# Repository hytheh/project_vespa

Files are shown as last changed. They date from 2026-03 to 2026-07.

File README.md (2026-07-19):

# Projet V.E.S.P.A. — prototype mk.2

**V**ision-**E**nabled **S**entry for the **P**rotection of **A**piaries

Tourelle optronique autonome de suivi prédictif par stéréo-vision, destinée à détecter,
suivre et neutraliser le frelon asiatique (*Vespa velutina nigrithorax*) en vol aux abords
d'une ruche, à l'aide d'un laser de puissance à collimation dynamique.

Projet de fin d'études — **ENSIL-ENSCI, Limoges** — filière Mécatronique (MIX 5), promotion 2026.
Antonin Delmas, Clément Desmedt, Clément Gilson — encadrement : Michel Ousset, Thierry Cortier.

> ### ⚠️ Statut : prototype semi-fonctionnel — projet clôturé, ouvert à reprise
>
> Ce dépôt est **archivé en l'état** à la fin du projet de fin d'études. Il est structuré
> et documenté pour être **repris par une équipe suivante**. Il n'est pas un produit fini :
> voir [État d'avancement](#état-davancement) et surtout
> **[docs/Difficultes_techniques.pdf](docs/Difficultes_techniques.pdf)**, qui recense les
> verrous levés et ceux qui restent ouverts.
>
> **Le laser de puissance (diode bleue 5,5 W — Classe 4) n'a jamais été mis sous tension.**
> C'était une décision de sécurité délibérée : le *watchdog* matériel qui conditionne
> l'autorisation de tir n'a jamais été implémenté. Ne pas alimenter la diode avant
> d'avoir lu [docs/annexes/securite_laser.md](docs/annexes/securite_laser.md).

---

## Documents

| Document | Contenu |
|---|---|
| **[Rapport technique](docs/Rapport_technique.pdf)** | Tout ce qu'il faut pour **reproduire** le système : matériel, câblage, système d'exploitation, firmware, compilation, calibration, mise en route. |
| **[Difficultés techniques](docs/Difficultes_techniques.pdf)** | Les **verrous non triviaux** rencontrés : ceux qui ont été levés (et comment), ceux qui ont été reportés (et pourquoi). À lire avant toute reprise. |
| **[Bibliographie](docs/Bibliographie.pdf)** | Sources du projet (biologie, vision, commande, optique, sécurité laser, matériel), chacune annotée de ce qu'elle a déterminé. Source BibTeX : [`docs/src/vespa.bib`](docs/src/vespa.bib). |
| [Rapport de PFE (soutenance)](docs/Rapport_PFE_2026_VESPA.pdf) | Le rapport rendu à la soutenance (mars 2026). Document historique, conservé tel quel. |

Annexes techniques (formats légers, tenus à jour avec le code) :
[protocole CAN](docs/annexes/protocole_can.md) ·
[câblage](docs/annexes/cablage.md) ·
[nomenclature / BOM](docs/annexes/bom.md) ·
[configuration Jetson](docs/annexes/jetson_setup.md) ·
[sécurité laser](docs/annexes/securite_laser.md) ·
[dette technique](docs/annexes/dette_technique.md)

---

## Architecture

Trois nœuds sur un bus **CAN 2.0B à 500 kbit/s**, plus un système auxiliaire de supervision.

```
                    ┌──────────────────────────────┐
                    │  VISION NODE                 │
                    │  Jetson Orin Nano Super 8 Go │
                    │  2x OV9281 global shutter    │
                    │  Stéréo 60 Hz + Kalman       │──┐
                    └──────────────────────────────┘  │
                                                      │
    ┌─────────────────────────────────┐               │   BUS CAN
    │  MOTION NODE                    │               │   500 kbit/s
    │  NUCLEO-G431RB                  │───────────────┤   11 bits
    │  2x X-NUCLEO-IHM16M1 (STSPIN830)│               │
    │  2x GM5208-12 + AS5048A · FOC   │               │
    └─────────────────────────────────┘               │
                                                      │
    ┌─────────────────────────────────┐               │
    │  COORDINATION NODE   ⚠ ABSENT   │───────────────┘
    │  ESP32 · collimation + tir      │
    │  + Watchdog (jamais implémenté) │
    └─────────────────────────────────┘
```

| Nœud | Cible | Rôle | État |
|---|---|---|---|
| **[vision_node](software/vision_node/)** | Jetson Orin Nano | Acquisition stéréo synchronisée matériellement (60 Hz), détection, triangulation, prédiction de Kalman, émission de la consigne | ✅ Fonctionnel (cible ArUco) |
| **[motion_node](software/motion_node/)** | STM32G431RB | Asservissement FOC en boucle fermée des deux axes pan/tilt sur la consigne reçue par CAN (la cinématique inverse `X,Y,Z → pan,tilt` est faite côté vision) | ✅ Servo FOC fonctionnel · intégration vision→moteur câblée, non validée sur banc |
| **[coordination_node](software/coordination_node/)** | ESP32 | Collimation dynamique, séquence de tir, **watchdog** et autorisation de tir | ❌ **Non implémenté** |
| **[common](software/common/)** | tous | Protocole CAN partagé (source unique de vérité) | ✅ Fonctionnel |

---

## État d'avancement

**Ce qui fonctionne, validé sur matériel réel :**

- **Vision.** Paire stéréo OV9281 déclenchée par le **PWM matériel du Tegra** (60 Hz), avec une
  dérive inter-caméras mesurée à **0,000 ms**. Chaîne zéro-copie V4L2 (mmap), suivi de cible,
  triangulation stéréo éparse, filtre de Kalman prédictif, émission des trames CAN.
- **Mouvement.** Asservissement FOC en boucle fermée des deux moteurs *pancake* GM5208-12
  sur encodeurs absolus AS5048A 14 bits. Butées logicielles, filtre de trajectoire,
  arrêt d'urgence matériel latché. Précision théorique 0,022°.
- **Protocole CAN.** Sérialisation/désérialisation partagée, développée sur bus virtuel
  `vcan0` puis **portée sur le bus physique sans changer une ligne**. Le Jetson a reçu
  **111 909 trames du STM32, sans une seule erreur** (`ip -s link show can0`, 21 mars 2026).

**Ce qui ne fonctionne pas, et pourquoi :**

| Verrou | Nature | Détail |
|---|---|---|
| 🟠 **Bus CAN — persistance** | À remettre en service | Le bus **a fonctionné** sur cuivre. `can0-pinmux.dtbo` est dans `/boot`, copie de référence dans [`jetson/dts/`](jetson/dts/). Piège : une mise à jour JetPack peut **effacer l'*overlay* de `/boot`** sans toucher à la ligne `OVERLAYS` qui le référence — le *bootloader* **n'émet aucune erreur**, `can0` existe toujours, mais ses broches restent `(MUX UNCLAIMED)` et le nœud émet dans le vide. **C'est une remise en état, pas une recherche** : remonter les transceivers avec le correctif 5 V, puis reconfirmer le sens émission. |
| 🔴 **Reconnaissance biologique** | Reporté | Le modèle **VespAI** est entraîné en RGB ; les capteurs sont monochromes. Le portage en Y8 (1 canal) produit un modèle rapide (10,3 ms, 100 fps) mais **inexploitable** : faux positifs massifs, incapacité à distinguer *V. velutina* de *V. crabro*. Remplacé par un **marqueur ArUco** servant de cible de substitution. |
| 🔴 **Tir laser** | Reporté (sécurité) | Aucun tir n'a été effectué. Le *watchdog* qui conditionne l'autorisation de tir n'existe pas. |
| 🔴 **Nœud de coordination** | Non commencé | Collimation dynamique, séquence de tir, watchdog : spécifiés, jamais codés. |

Le détail complet — symptômes, causes racines, correctifs — est dans
**[Difficultés techniques](docs/Difficultes_techniques.pdf)**.

---

## Reprendre le projet : par où commencer

1. Lire **[Difficultés techniques](docs/Difficultes_techniques.pdf)** en entier. Beaucoup de
   pièges de ce système sont invisibles dans le code (transceivers CAN contrefaits, broche
   `PA2` qui coupe la liaison série, impédance interne cachée de 4 kΩ sur le GPIO du Jetson…).
2. Reproduire l'environnement avec le **[Rapport technique](docs/Rapport_technique.pdf)**.
3. Attaquer les chantiers dans cet ordre — c'est l'ordre des dépendances :

   | # | Chantier | Pourquoi d'abord |
   |---|---|---|
   | 1 | **Remettre le CAN physique en service** | Remonter les transceivers avec le correctif 5 V. Le bus a déjà fonctionné : c'est du remontage, pas du débogage. |
   | 2 | **Implémenter le watchdog** (ESP32) | Condition *sine qua non* de toute mise sous tension du laser Classe 4. |
   | 3 | **Constituer un jeu de données monochrome** et réentraîner un détecteur | Rend au système sa fonction biologique ; remplace le marqueur ArUco. |
   | 4 | **Collimation dynamique + essais optiques** | Loi de commande établie, mécanisme spécifié, jamais assemblé ni étalonné. |
   | 5 | **Gestion multi-cibles** | Un seul filtre de Kalman aujourd'hui ; il en faut un par cible + association de données. |

---

## Structure du dépôt

```
project_vespa/
├── docs/                    Rapports (PDF + sources LaTeX), annexes, bibliographie, références
│   ├── src/                 Sources LaTeX + vespa.bib + figures (figs/)
│   ├── annexes/             Câblage, protocole CAN, BOM, setup Jetson, sécurité, dette technique
│   └── references/          Articles, datasheets, études préparatoires (IA)
├── hardware/
│   └── mechanical/          CAO : assemblages STEP, maillages imprimés, plateaux PrusaSlicer, moteur — voir son README
│                            (les modèles éditables restent sur le 3DEXPERIENCE de l'école)
├── jetson/                  Configuration système du Jetson (overlays, services CAN, extlinux)
├── simulation/              Scripts MATLAB de dimensionnement (vision + optique laser)
└── software/
    ├── common/              Protocole CAN partagé (C, portable STM32/ESP32/Linux)
    ├── vision_node/         Jetson — C++17 / OpenCV / V4L2 / SocketCAN (CMake)
    ├── motion_node/         STM32G431RB — SimpleFOC / FDCAN (PlatformIO)
    ├── coordination_node/   ESP32 — non implémenté (spécification uniquement)
    ├── tools/               Outils de maintenance : calibration stéréo, exposition, viewport
    └── legacy_mk1_bench/    Banc de caractérisation mk.1 (Arduino Uno) — annexes du rapport PFE
```

---

## Démarrage rapide

Prérequis : Jetson Orin Nano sous **JetPack 6.2.1**, avec le noyau Arducam et les *overlays*
installés (voir [configuration Jetson](docs/annexes/jetson_setup.md) — cette étape n'est
**pas** optionnelle, les caméras ne fonctionnent pas sans).

```bash
# --- Nœud de vision (Jetson) ---
sudo apt install libopencv-dev libi2c-dev libzmq3-dev cppzmq-dev nlohmann-json3-dev v4l-utils can-utils
cd software/vision_node && mkdir -p build && cd build
cmake .. && make -j6
sudo ./vision_node                 # accès requis à /sys/class/pwm et /dev/video*

# --- Nœud de mouvement (STM32, depuis le PC de développement) ---
cd software/motion_node
pio run -t upload                  # sonde ST-LINK
pio device monitor -b 115200

# --- Outils de maintenance (Jetson, headless : interface web) ---
# Les serveurs web n'écoutent QUE sur localhost (127.0.0.1). Sur un Jetson
# headless, y accéder par un tunnel SSH : ssh -L 5002:localhost:5002 <jetson>
cd software/tools/calib_stereo && ./run_calibration.sh      # http://localhost:5002
```

> Le nœud de vision et l'outil de calibration d'exposition (`calib_exposition`) accèdent
> tous deux directement au bus I²C. Un verrou d'exclusion mutuelle
> (`/tmp/vespa_hardware.lock`) les empêche de le toucher en même temps : **lancer les deux à
> la fois échouera volontairement**, ce n'est pas un bug. (Les outils `calib_stereo` et
> `viewport_live` ne prennent pas le verrou : ils ne font que consommer le flux ZMQ d'un
> producteur C++ qui, lui, le détient.)

---

## Avertissement sécurité

L'effecteur prévu est une diode laser **bleue de 5,5 W — Classe 4 (IEC 60825-1)**. À la densité
de puissance visée (≈ 2 200 W/cm² sur un spot de 0,53 mm), il n'existe **aucune distance sûre
en intérieur** : lésions oculaires irréversibles y compris sur réflexion diffuse, brûlures
cutanées, risque d'incendie. Lunettes **OD7+ (190–550 nm)** et interlock matériel obligatoires.

⚠️ Le mécanisme de collimation dynamique réduit le risque d'**incendie** (seuil d'embrasement
franchi sur ≈ 50 mm autour de la cible), mais **pas** le risque **oculaire**, qui persiste sur
près de **200 m**. Ne pas se croire protégé par la défocalisation.

Le dispositif de tir de ce dépôt est **incomplet et non validé**. Voir
[docs/annexes/securite_laser.md](docs/annexes/securite_laser.md) avant toute manipulation.

---

## Licence

Le code et la documentation **originaux** de ce dépôt sont publiés sous licence **MIT**
(voir [`LICENSE`](LICENSE)) — cohérent avec le statut « ouvert à reprise ».

Composants tiers, sous leurs licences respectives :

- `software/vision_node/include/zmq.hpp` — **cppzmq 4.11.0**, licence MIT (en-tête conservé).
- Les articles scientifiques de `docs/references/articles/` restent la propriété de leurs
  auteurs/éditeurs ; ceux conservés ici sont en Open Access **CC-BY**. Les *datasheets*
  constructeurs (`docs/references/datasheets/`) appartiennent à leurs fabricants respectifs.

Pour reprendre le projet, voir [`CONTRIBUTING.md`](CONTRIBUTING.md). Pour le citer, voir
[`CITATION.cff`](CITATION.cff).

---

## Note sur l'usage de l'IA

Ce projet a été développé avec une assistance importante de modèles de langage (rédaction,
débogage, état de l'art), comme documenté dans le préambule du rapport de PFE. Les archives
de conversations ayant mené à la résolution des verrous clés ont été conservées et ont servi
à rédiger le document [Difficultés techniques](docs/Difficultes_techniques.pdf).
Plusieurs verrous majeurs — transceivers CAN contrefaits, impédance cachée du GPIO,
profondeur de champ létale réelle — ont été identifiés **contre** l'avis de l'IA, par la mesure.

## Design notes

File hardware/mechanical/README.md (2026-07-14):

# Mécanique — CAO et pièces imprimées 3D

Géométrie du prototype VESPA mk.2 : assemblages STEP, maillages imprimés, projets
PrusaSlicer qui les ont produits.

```
hardware/mechanical/
├── cad/            assemblages STEP (AP242, mm)
├── print/          maillages des pièces imprimées (STL / 3MF)
│   └── plates/     projets PrusaSlicer des plateaux lancés
└── motor/          caractérisation du moteur GM5208-12
```

---

## Fichiers éditables

La CAO est faite sous **3DEXPERIENCE R2026x**, sur la **plateforme privée de l'école**.
Chez Dassault Systèmes les objets natifs (`3D Shape`, `Physical Product`) sont des
enregistrements de base de données, pas des fichiers : ils ne sortent pas de la plateforme.

**Les modèles paramétriques — arbre de construction, esquisses, contraintes — sont sur le
3DEXPERIENCE de l'école, et nulle part ailleurs.** La colonne *Item 3DX* des tableaux
ci-dessous donne, pour chaque pièce, le nom sous lequel elle y est enregistrée : c'est la
clé de recherche dans la base.

Ce qui sort de la plateforme, et qui est ici, est l'export **STEP** (ISO 10303 AP242) :
géométrie exacte — surfaces, arêtes, topologie — lisible par SolidWorks, Fusion, FreeCAD,
Onshape, CATIA. Il porte la géométrie, pas l'historique de conception. Les maillages
(`.stl`, `.3mf`) ne portent ni l'un ni l'autre.

---

## Convention de nommage

```
VESPA_<Sous-ensemble>_<Pièce>_<Révision>.<ext>
```

| Champ | Règle | Exemple |
|---|---|---|
| `Sous-ensemble` | Où la pièce se monte | `Turret`, `Frame`, `Link`, `Base`, `Camera`, `Optics` |
| `Pièce` | Ce qu'elle est | `MotorMount`, `FrontShield`, `LinkC` |
| `Révision` | Lettre.chiffre, croissante | `A.1`, `A.2`, `A.3` |

Les assemblages prennent `ASY` comme sous-ensemble ; le suffixe `_WIP` marque un assemblage
inachevé. Les plateaux d'impression sont préfixés `PLATE_`.

Les noms d'origine (préfixe `ADEL_`, espaces, parenthèses) ont été normalisés. Le nom
d'origine est conservé dans la colonne *Item 3DX* : c'est la clé de recherche dans la base
de l'école.

---

## Assemblages — `cad/`

| Fichier | Item 3DX | Rév. | Contenu | État |
|---|---|---|---|---|
| [`VESPA_ASY_FrameBase_A.2.step`](cad/VESPA_ASY_FrameBase_A.2.step) | `ADEL_VESPA_Frame_Base_ASY` | A.2 | **Le démonstrateur présenté** : tourelle 2 axes, 2× GM5208-12, module laser non câblé, 6× roulement 604ZZ. Les caméras n'y sont pas modélisées | Assemblé, monté |
| [`VESPA_ASY_Turret_A.2_WIP.step`](cad/VESPA_ASY_Turret_A.2_WIP.step) | `ADEL_VESPA_ASY_Turret` | A.2 | **Produit complet** : Jetson Orin Nano, 2× OV9281, laser, et le **tube optique** — lentille Ø63 f100 sur bague, portée par l'actionneur linéaire 35 mm : c'est le mécanisme de collimation dynamique | Inachevé, jamais assemblé |
| [`VESPA_ASY_Base_A.1_WIP.step`](cad/VESPA_ASY_Base_A.1_WIP.step) | `ADEL_VESPA_ASY_Base_mk2` | A.1 | Embase du produit complet : moyeu + jambe | Inachevé, jamais imprimé |
| [`VESPA_Bench_BoardPlate_A.1.step`](cad/VESPA_Bench_BoardPlate_A.1.step) | `ADEL_VESPA_Board_Bench` | A.1 | Platine de banc, 160 × 246 × 52 mm, portant les cartes électroniques. Matériel d'établi, hors machine | — |

`VESPA_ASY_Turret_A.2_WIP.step` pèse **83 Mo** : l'essentiel est le modèle fournisseur du
kit de développement Jetson Orin Nano publié par NVIDIA, modélisé jusqu'aux résistances
0402. La géométrie propre à VESPA y est marginale en volume.

`cad/` ne contient **que des assemblages** : il n'existe pas d'export STEP pièce à pièce.
Une pièce seule s'obtient en l'isolant dans l'assemblage, ou depuis 3DEXPERIENCE.

---

## Index des pièces imprimées

Quantités telles que définies dans l'assemblage.

### Châssis 2 axes — `VESPA_ASY_FrameBase_A.2`

| Pièce | Qté | Maillage | Plateau | Item 3DX |
|---|---:|---|---|---|
| `Frame_BaseA` | 1 | [`A.2`](print/VESPA_Frame_BaseA_A.2.stl) | — | `ADEL_VESPA_Frame_BaseA` |
| `Frame_BaseB` | 1 | [`A.2`](print/VESPA_Frame_BaseB_A.2.stl) | — | `ADEL_VESPA_Frame_BaseB` |
| `Frame_JointB2` | 1 | [`A.1`](print/VESPA_Frame_JointB2_A.1.stl) | [`Structural_x4`](print/plates/PLATE_Structural_x4.3mf) | `ADEL_VESPA_Frame_JointB2` |
| `Frame_LinkB1` | 1 | [`A.1`](print/VESPA_Frame_LinkB1_A.1.stl) | — | `ADEL_VESPA_Frame_LinkB1` |
| `Frame_LinkC` | 1 | [`A.3`](print/VESPA_Frame_LinkC_A.3.stl) | — | `ADEL_VESPA_Frame_LinkC` |
| `Frame_LinkA` | 1 | ⬜ absent | — | `ADEL_VESPA_Frame_LinkA` |
| `Link_BracketLeft` | 1 | [`A.1`](print/VESPA_Link_BracketLeft_A.1.stl) | [`Structural_x4`](print/plates/PLATE_Structural_x4.3mf) | `ADEL_VESPA_Link_BracketLeft` |
| `Link_BracketRight` | 1 | [`A.1`](print/VESPA_Link_BracketRight_A.1.stl) | — | `ADEL_VESPA_Link_BracketRight` |
| `Turret_MotorPlate` | 1 | [`A.1`](print/VESPA_Turret_MotorPlate_A.1.stl) | [`Structural_x4`](print/plates/PLATE_Structural_x4.3mf) | `ADEL_VESPA_Turret_MotorPlate` |
| `Turret_BearingPlate` | 1 | [`A.1`](print/VESPA_Turret_BearingPlate_A.1.stl) | — | `ADEL_VESPA_Turret_BearingPlate` |
| `Turret_ShieldLite` | 1 | [`A.1`](print/VESPA_Turret_ShieldLite_A.1.stl) | [`Structural_x4`](print/plates/PLATE_Structural_x4.3mf) | `ADEL_VESPA_Turret_ShieldLite` |

### Tourelle complète — `VESPA_ASY_Turret_A.2_WIP`

| Pièce | Qté | Maillage | Plateau | Item 3DX |
|---|---:|---|---|---|
| `Turret_RailType1` | 2 | [`A.2`](print/VESPA_Turret_RailType1_A.2.3mf) | [`RailType1_x2`](print/plates/PLATE_RailType1_x2.3mf) | `ADEL_VESPA_Turret_Rail_Type1` |
| `Turret_RailType2` | 2 | [`A.2`](print/VESPA_Turret_RailType2_A.2.3mf) | [`RailType2_x2`](print/plates/PLATE_RailType2_x2.3mf) | `ADEL_VESPA_Turret_RailType2` |
| `Turret_XFrame1Top` | 2 | [`A.1`](print/VESPA_Turret_XFrame1Top_A.1.3mf) | — | `ADEL_VESPA_Turret_XFrame1Top` |
| `Turret_FrontShield` | 1 | [`A.1`](print/VESPA_Turret_FrontShield_A.1.3mf) | [`flat`](print/plates/PLATE_FrontShield_flat.3mf) · [`tilted`](print/plates/PLATE_FrontShield_tilted.3mf) | `ADEL_VESPA_Turret_FrontShield` |
| `Turret_MotorMount` | 1 | [`A.1`](print/VESPA_Turret_MotorMount_A.1.3mf) | [`BearingMount_MotorMount`](print/plates/PLATE_BearingMount_MotorMount.3mf) | `ADEL_VESPA_Turret_MotorMount` |
| `Turret_BearingMount` | 1 | ⬜ absent — géométrie dans le plateau | [`BearingMount_MotorMount`](print/plates/PLATE_BearingMount_MotorMount.3mf) | `ADEL_VESPA_Turret_BearingMount` |
| `Turret_LABracket` | 1 | [`A.1`](print/VESPA_Turret_LABracket_A.1.3mf) | — | `ADEL_VESPA_Turret_LABracket` |
| `Turret_LaserMountFront` | 1 | [`A.2`](print/VESPA_Turret_LaserMountFront_A.2.3mf) | — | `ADEL_VESPA_Turret_LaserMountFront` |
| `Turret_CamBracket` | 2 | ⬜ absent | — | `ADEL_VESPA_Turret_CamBracket` |
| `Turret_JetsonHolder_L` | 1 | ⬜ absent | — | `ADEL_VESPA_Turret_JetsonHolder_L` |
| `Turret_JetsonHolder_R` | 1 | ⬜ absent | — | `ADEL_VESPA_Turret_JetsonHolder_R` |
| `LensRing` | 1 | ⬜ absent | — | `ADEL_VESPA_LensRing` |
| `Linear35_CarriageBody` | 1 | ⬜ absent | — | `ADEL_VESPA_Linear35_CarriageBody` |

### Embase — `VESPA_ASY_Base_A.1_WIP`

| Pièce | Qté | Maillage | Plateau | Item 3DX |
|---|---:|---|---|---|
| `Base_Hub` | 1 | [`A.1`](print/VESPA_Base_Hub_A.1.stl) | — | `ADEL_VESPA_Base_Hub` |
| `Base_Leg` | 1 | ⬜ absent | — | `ADEL_VESPA_Base_Leg` |

### Hors assemblage

| Pièce | Maillage | Item 3DX | Statut |
|---|---|---|---|
| `Optics_LensHolderSpacer` | [`A.1`](print/VESPA_Optics_LensHolderSpacer_A.1.3mf) | `ADEL_VESPA_Temporary_LensHolderSpacer` | Cale provisoire de porte-lentille. Pièce d'appoint, n'apparaît dans aucun assemblage |
| `Camera_CarrierB` | [`A.1`](print/VESPA_Camera_CarrierB_A.1.3mf) | `ADEL_SK_Carrier_B` | Support de carte porteuse, 53 × 56 × 4,6 mm. Absent des assemblages A.2 |

**Légende :** ⬜ maillage absent du dépôt. La pièce existe dans le STEP ; son export
d'impression n'a pas été retrouvé.

---

## Paramètres d'impression

Imprimante **Prusa CORE One**, buse **0,4 mm haut débit**, **PLA**, couche **0,2 mm**,
plateau **60 °C**.

Les six fichiers de [`print/plates/`](print/plates/) sont des projets PrusaSlicer complets :
le `.3mf` contient l'orientation de pose, les supports et le profil utilisés.

| Plateau | Pièces | Profil | Remplissage | Périm. | Buse | Supports |
|---|---|---|---|---:|---:|---|
| [`PLATE_Structural_x4`](print/plates/PLATE_Structural_x4.3mf) | `Turret_MotorPlate`, `Turret_ShieldLite`, `Link_BracketLeft`, `Frame_JointB2` | `0.20mm STRUCTURAL` — **Prusament PLA** | gyroïde 25 % | 2 | 230 °C | peints |
| [`PLATE_RailType1_x2`](print/plates/PLATE_RailType1_x2.3mf) | 2× `Turret_RailType1` | `0.20mm SPEED` | gyroïde 25 % | 3 | 225 °C | peints |
| [`PLATE_RailType2_x2`](print/plates/PLATE_RailType2_x2.3mf) | 2× `Turret_RailType2` | `0.20mm SPEED` | gyroïde 25 % | 3 | 225 °C | peints |
| [`PLATE_FrontShield_flat`](print/plates/PLATE_FrontShield_flat.3mf) | `Turret_FrontShield`, pose à plat | `0.20mm SPEED` | gyroïde 25 % | 3 | 225 °C | peints |
| [`PLATE_FrontShield_tilted`](print/plates/PLATE_FrontShield_tilted.3mf) | `Turret_FrontShield`, pose inclinée | `0.20mm SPEED` | gyroïde 25 % | 3 | 225 °C | automatiques |
| [`PLATE_BearingMount_MotorMount`](print/plates/PLATE_BearingMount_MotorMount.3mf) | `Turret_BearingMount`, `Turret_MotorMount` | `0.20mm SPEED` | grille 15 % | 2 | 225 °C | automatiques |

Les deux plateaux `FrontShield` sont deux orientations de pose de la même pièce A.1.

`STRUCTURAL` est le seul profil en Prusament PLA à 230 °C, avec 4 couches pleines en fond ;
il porte les quatre pièces qui reprennent les efforts des moteurs. Les cinq autres plateaux
sont en `SPEED`. *Supports peints* = générés uniquement sur les zones marquées
(`support_material_auto = 0`).

---

## Composants du commerce présents dans la CAO

Modélisés pour l'encombrement et les fixations, **non fabriqués**. Références et prix dans
la [nomenclature](../../docs/annexes/bom.md).

| Composant | Item 3DX | Où |
|---|---|---|
| Moteur *pancake* GM5208-12 | `ADEL_VESPA_5208BLDC_ASY` | FrameBase (×2), Turret (×1) |
| Module laser 5,5 W — corps, carte, lentille, capot acrylique, ventilateur 40×15 | `ADEL_VESPA_ASY_Laser` | FrameBase, Turret |
| Jetson Orin Nano — kit de développement | `ADEL_NvidiaJetsonOrinNano` | Turret |
| Caméra OV9281 UC788B | `ADEL_VESPA_OV9281_CameraModuleUC788B` | Turret (×2) |
| Actionneur linéaire 35 mm — rails Ø3, douilles, moteur pas-à-pas 20 mm | `ADEL_VESPA_ASY_Linear35Actuator` | Turret |
| Lentille asphérique K9 Ø63 f100 | `ADEL_VESPA_Lens63d100f` | Turret |
| Roulements 604ZZ (×6) et 6810 (×1) | `ADEL_VESPA_604ZZ_Bearing`, `ADEL_VESPA_bearing_6810O` | FrameBase, Turret |
| Goupilles 4×20, vis CHc M4×40 | `ADEL_VESPA_HRDW_Pin4x20`, `ADEL_VESPA_Laser_~Vis_Chc_M4x40` | FrameBase |

---

## Moteur

[`motor/GM5208-12.json`](motor/GM5208-12.json) — caractérisation du moteur *pancake*
GM5208-12 au format ST Motor Profiler, exploitable directement par le
*ST Motor Control Workbench*.

| Paramètre | Valeur |
|---|---|
| Type | PMSM *pancake* (gimbal), 14 aimants |
| Paires de pôles | **7** |
| Résistance statorique `Rs` | 7,48 Ω |
| Inductance `Ls` | 4,49 mH |
| Tension nominale | 23,6 V |
| Courant nominal | 1,5 A |
| Constante de FEM | 32,96 |
| Encodeur associé | AS5048A, magnétique absolu **14 bits** (0,022°) |

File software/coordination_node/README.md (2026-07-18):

# `coordination_node` — NON IMPLÉMENTÉ

> **Ce nœud n'existe pas.** Ce dossier ne contient aucun code : uniquement sa spécification.
> Il est conservé dans l'arborescence parce que le protocole CAN réserve ses identifiants et
> que le reste du système est écrit en supposant son existence future.

**Cible matérielle prévue :** ESP32 **bi-cœur** (ESP32 classique ou ESP32-S3).

> ⚠️ L'ESP32-**C3** SuperMini listé dans la nomenclature d'origine est **mono-cœur**
> (RISC-V) : il ne peut pas fournir le « cœur CPU dédié » exigé par le watchdog ci-dessous.
> Deux options pour une reprise : (a) viser un ESP32/ESP32-S3 **bi-cœur** pour réserver un
> cœur au superviseur ; ou (b) sur mono-cœur, réaliser l'isolation par une **tâche FreeRTOS
> de priorité maximale épinglée** + le **watchdog matériel (TWDT)** de la puce. L'option (a)
> est recommandée pour un organe qui conditionne un laser de Classe 4.

---

## Pourquoi c'est le chantier n°2 de toute reprise

Ce nœud porte le **watchdog**. Le watchdog est la **condition *sine qua non*** de toute mise
sous tension du laser de Classe 4. Tant qu'il n'existe pas, **le laser ne doit pas être
alimenté** — et il ne l'a jamais été.

Voir [`docs/annexes/securite_laser.md`](../../docs/annexes/securite_laser.md).

---

## Les trois fonctions à implémenter

### 1. Watchdog (priorité absolue)

Superviseur centralisé, **sur un cœur CPU dédié** (voir la note matérielle ci-dessus), au
plus près de l'organe dangereux.

- Écoute les *heartbeats* périodiques de tous les nœuds : `HB_VISION` (`0x100`),
  `HB_MOTION` (`0x110`), `HB_COORD` (`0x120`).
- Chaque *heartbeat* porte un `uint8_t system_state` : `0x00` OK, `0x01` WARNING,
  `0x02` FAULT (énumération normative dans `can_protocol.h`).
- **Timeout par nœud (à figer) :** valeur proposée **200 ms** de silence glissant. Le
  firmware actuel émet les *heartbeats* à **1 Hz** (`motion_node`) ; pour un interlock à
  200 ms, il faut **relever la cadence** sur le lien critique (p. ex. ≥ 10 Hz), ce qui est
  un préalable d'implémentation.
- **Déclenche la mise en sécurité si** : un nœud signale `FAULT`, **ou** un nœud cesse
  d'émettre au-delà du *timeout* ci-dessus.
- **Signal d'interlock — ligne physique, pas une trame CAN.** Le superviseur pilote une
  sortie GPIO dédiée `INTERLOCK_EN`, **fail-safe** (niveau **bas = tir interdit** ; l'organe
  de tir n'est armé que sur niveau haut maintenu). Elle est **indépendante du bus** pour ne
  pas dépendre de la panne qu'elle doit traiter (cf. l'avertissement ci-dessous).
- La mise en sécurité est **matérielle** : coupure de l'**alimentation générale** et passage
  de `INTERLOCK_EN` au niveau bas. Pendant le temps de décharge des condensateurs, l'ordre
  de tir est en outre inhibé au niveau logiciel.

> ⚠️ Un superviseur qui dépendrait du bus pour couper le courant serait vulnérable à la
> panne même qu'il doit traiter. La coupure doit être physique et par défaut fermée
> (*fail-safe*).

### 2. Séquence de tir

- Consomme `FIRE_CMD` (`0x010`) émis par le `vision_node` — identifiant le plus faible du
  protocole, donc **priorité absolue** à l'arbitrage CAN.
- N'autorise le tir que si **toutes** les conditions sont réunies : cible verrouillée,
  watchdog nominal, interlock fermé, collimateur en position.

### 3. Collimation dynamique

- Pilote la lentille mobile **L2** (actionneur linéaire + TMC2209).
- Publie sa position absolue sur `POS_COORD` (`0x040`, `int32_t position_mm`).
- La **loi de commande est déjà établie** (relations de conjugaison de Descartes, approximée
  par un polynôme à 1e-4 mm près) — voir le rapport de soutenance §10.2 et
  `simulation/optique/Laser_Optics_v1.m`.

---

## Trames CAN réservées

| ID | Trame | Sens | Charge utile |
|---|---|---|---|
| `0x010` | `FIRE_CMD` | ← vision | `uint8_t fire_order` (`0x01` = tir) |
| `0x040` | `POS_COORD` | → vision | `int32_t position_mm` (collimateur) |
| `0x120` | `HB_COORD` | → (watchdog) | `uint8_t system_state` |
| `0x210` | `DBG_COORD` | → broadcast | Débogage |

Définition normative : [`software/common/can_protocol.h`](../common/can_protocol.h).
Le protocole est **partagé** — l'implémentation de ce nœud doit lier `software/common/`,
et surtout **ne pas redéfinir les structures**.

---

## Point de départ

Le code CAN est portable : `software/common/can_utils.c` compile sur STM32, ESP32 et Linux.
Un ESP32 dispose d'un contrôleur CAN natif (TWAI), compatible avec le bus 500 kbit/s du
projet, moyennant un transceiver.

⚠️ **Attention au transceiver.** Les modules WCMCU-230 approvisionnés pour le projet sont
des **contrefaçons 5 V** vendues pour des SN65HVD230 3,3 V (boîtiers poncés et re-marqués).
Ils fonctionnent, mais **alimentés en 5 V**, avec un pont diviseur 1 kΩ / 2 kΩ sur la sortie
`CRX`. Vérifier ce que vous avez en main avant de câbler — voir
[`docs/annexes/bom.md`](../../docs/annexes/bom.md).

Le plus simple pour démarrer reste de développer sur `vcan0`, comme l'ont fait les autres
nœuds : l'interface est indiscernable d'un bus réel côté SocketCAN, et le passage au matériel
n'a demandé aucune modification du code. Voir
[`docs/Difficultes_techniques.pdf`](../../docs/Difficultes_techniques.pdf).

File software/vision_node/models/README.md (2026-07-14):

# `models/` — moteur d'inférence de la voie abandonnée

## `vespai.engine` (16 Mo)

Moteur **TensorRT sérialisé** issu du portage du modèle **VespAI**
([O'Shea-Wheller et al., 2024](../../../docs/references/articles/OSheaWheller2024_VespAI_CommsBiology.pdf)),
construit sur le Jetson Orin Nano du projet.

> **Ce fichier n'est utilisé par aucun code du dépôt.** Ni le `CMakeLists.txt`, ni
> `vision_node`, ni aucun outil ne le chargent. Il est conservé comme **trace de la voie
> d'inférence explorée puis abandonnée**, pas comme un composant du système livré.

### Pourquoi il n'est pas utilisé

VespAI est entraîné en **RGB** ; les capteurs OV9281 du projet sont **monochromes**. Le
portage en Y8 (1 canal) produit un modèle **rapide** — 10,3 ms par inférence, soit 100 fps,
donc parfaitement compatible avec la cadence de 60 Hz — mais **inexploitable en pratique** :
faux positifs massifs, et incapacité à distinguer *Vespa velutina* de *Vespa crabro*, ce qui
est précisément la discrimination que le système doit faire.

La détection biologique a donc été remplacée par un **marqueur ArUco** servant de cible de
substitution. Voir le README racine et `docs/Difficultes_techniques.pdf`.

### Pourquoi il n'est pas réutilisable tel quel

Un moteur TensorRT sérialisé **n'est pas portable** : il est lié à la version de TensorRT et
à l'architecture GPU qui l'ont produit. Il ne se rechargera pas sur une autre machine, ni
même sur ce Jetson après une mise à jour de JetPack.

**Le modèle source (ONNX / poids) n'est pas au dépôt.** Ce binaire ne permet donc **pas** de
repartir de l'existant.

### Ce qu'il faut faire à la reprise

Ne pas essayer de réutiliser ce fichier. Le chantier est de **constituer un jeu de données
monochrome** et de **réentraîner** un détecteur dessus (chantier n°3 du README racine) — ce
qui rend de toute façon ce moteur caduc.

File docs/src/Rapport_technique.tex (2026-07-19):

\documentclass[11pt,a4paper]{article}
\usepackage{vespa_style}

\begin{document}

\vespatitlepage
  {Rapport technique}
  {Guide de reproduction — matériel, système, firmware}
  {Document de clôture — juillet 2026\\
   Tout ce qui est nécessaire pour reconstruire le prototype mk.2 depuis zéro.}

\tableofcontents
\newpage

% =====================================================================
\section{Objet de ce document}

Ce document est un \textbf{guide de reproduction}. Il décrit, dans l'ordre où il faut les
exécuter, les opérations permettant de reconstituer le prototype \vespa{} mk.2 :
approvisionnement, câblage, installation système, compilation des deux firmwares,
calibration, mise en route.

Il ne justifie pas les choix de conception — cela relève du rapport de soutenance
(\fichier{docs/\allowbreak Rapport\_PFE\_2026\_VESPA.pdf}). Il ne raconte pas non plus les impasses —
cela relève de \fichier{docs/\allowbreak Difficultes\_techniques.pdf}.

\begin{avertissement}[Lisez d'abord « Difficultés techniques »]
Plusieurs étapes de ce guide comportent des pièges qui \textbf{ne se voient pas} et dont le
symptôme n'a aucun rapport apparent avec la cause (une broche qui coupe la console série,
un outil NVIDIA qui détruit la configuration des caméras). Elles sont signalées ici, mais
elles ne sont \emph{expliquées} que dans le document des difficultés. Le temps passé à le
lire sera regagné plusieurs fois.
\end{avertissement}

\paragraph{État de ce qui est reproductible.} Ce guide mène à un système qui \textbf{suit
une cible ArUco en 3D et oriente la tourelle}. Il ne mène pas à un système qui reconnaît un
frelon (modèle indisponible), ni qui tire (watchdog non implémenté, laser jamais mis sous
tension). Voir la synthèse en fin de document.

% =====================================================================
\section{Architecture matérielle}

\begin{center}
\begin{tabularx}{\textwidth}{@{}llX@{}}
\toprule
\textbf{N\oe ud} & \textbf{Calculateur} & \textbf{Rôle} \\
\midrule
\texttt{vision\_node} & Jetson Orin Nano Super 8~Go &
Acquisition stéréo synchronisée, détection, triangulation, prédiction, émission de la
consigne \\
\addlinespace
\texttt{motion\_node} & NUCLEO-G431RB &
Asservissement FOC en boucle fermée des axes \textsc{pan} et \textsc{tilt} \\
\addlinespace
\texttt{coordination\_node} & ESP32 &
Collimation, tir, watchdog — \textcolor{vespared}{\textbf{non implémenté}} \\
\bottomrule
\end{tabularx}
\end{center}

\noindent
Les n\oe uds communiquent sur un \textbf{bus CAN 2.0B à 500~kbit/s} (trames standard
11~bits). Le dictionnaire de données complet est en annexe
(\fichier{docs/annexes/protocole\_can.md}) ; sa définition normative est
\fichier{software/common/can\_protocol.h}.

\begin{figure}[htbp]
  \centering
  
  \caption{Architecture système. Les trois n\oe uds échangent sur le bus CAN ; le
  \emph{watchdog}, porté par le n\oe ud de coordination, commande la coupure de
  l'alimentation générale. \textbf{Le n\oe ud de coordination — donc le watchdog et le tir —
  n'a jamais été implémenté} : c'est la raison pour laquelle le laser n'a jamais été mis
  sous tension.}
  \label{fig:arch-global}
\end{figure}

% =====================================================================
\section{Nomenclature (BOM)}
\label{sec:bom}

Nomenclature du prototype mk.2, \textbf{telle que réellement montée}. Total
\textbf{840,74~\euro{}} TTC. Les prix de la colonne « Prix TTC » sont des prix de ligne
(quantité comprise), et non des prix unitaires.

\begin{center}
\begin{tabularx}{\textwidth}{@{}Xlr@{}}
\toprule
\textbf{Élément} & \textbf{Qté} & \textbf{Prix TTC} \\
\midrule
\multicolumn{3}{@{}l}{\textit{\textcolor{vespagray}{Calcul et électronique}}} \\
Jetson Orin Nano Super Developer Kit & 1 & 311,18~\euro{} \\
NUCLEO-G431RB \textit{\footnotesize (MCU du \fichier{motion\_node})} & 1 & 22,08~\euro{} \\
X-NUCLEO-IHM16M1 (STSPIN830) \textit{\footnotesize (étages de puissance)} & 2 & 36,22~\euro{} \\
ESP32-C3 SuperMini \textit{\footnotesize (coordination — non implémentée)} & 1 & 4,29~\euro{} \\
Alimentation AC-DC 24~V / 150~W & 1 & 5,29~\euro{} \\
Transceivers CAN WCMCU-230 (lot de 10) \textcolor{vespared}{\textbf{(contrefaits)}}
  & 1 & 5,19~\euro{} \\
TMC2209 (lot de 4) \textit{\footnotesize (collimation)} & 1 & 9,09~\euro{} \\
\addlinespace
\multicolumn{3}{@{}l}{\textit{\textcolor{vespagray}{Vision}}} \\
Module caméra Arducam OV9281 1~MP monochrome \emph{global shutter} & 2 & 142,59~\euro{} \\
Objectif M12 5~MP 4,6~mm sans distorsion & 2 & 9,29~\euro{} \\
\addlinespace
\multicolumn{3}{@{}l}{\textit{\textcolor{vespagray}{Mécanique et actionneurs}}} \\
iFlight iPower GM5208-12 + encodeur AS5048A (paire) & 1 & 134,99~\euro{} \\
Actionneur linéaire course 35~mm & 1 & 20,42~\euro{} \\
Capteur photoélectrique en U \textit{\footnotesize (prise d'origine)} & 1 & 2,54~\euro{} \\
\addlinespace
\multicolumn{3}{@{}l}{\textit{\textcolor{vespagray}{Optique de tir}}} \\
\textbf{Diode laser bleue 5,5~W} \textcolor{vespared}{\textbf{(Classe 4)}} & 1 & 83,69~\euro{} \\
Lentille asphérique K9 D63 F100 \textit{\footnotesize (L2, focale 100~mm)} & 1 & 23,59~\euro{} \\
\addlinespace
\multicolumn{3}{@{}l}{\textit{\textcolor{vespagray}{Sécurité — non optionnel}}} \\
\textbf{Lunettes de protection OD7+ CE 190--550~nm} & 1 & 30,29~\euro{} \\
\midrule
\textbf{TOTAL} & & \textbf{840,74~\euro{}} \\
\bottomrule
\end{tabularx}
\end{center}

\begin{avertissement}[Les transceivers CAN du lot sont des contrefaçons]
Les modules \fichier{WCMCU-230} approvisionnés, vendus comme portant un \textbf{SN65HVD230}
de Texas Instruments (3,3~V), sont des \textbf{clones 5~V} : boîtiers poncés et re-marqués au
laser. Un montage 3,3~V « théorique » avec ces modules donne un bus \textbf{asymétrique} —
réception parfaite, émission morte.

\textbf{Montage qui fonctionne avec ces modules :} alimentation \textbf{5~V} sur la broche
sérigraphiée « \texttt{3V3} », et \textbf{pont diviseur 1~k$\Omega$ / 2~k$\Omega$} sur la
sortie \texttt{CRX} pour la ramener à 3,3~V vers le Jetson. \emph{Ne pas} employer de
convertisseur de niveau à MOSFET : trop lent à 500~kbit/s.

\textbf{Avec de vrais SN65HVD230}, câbler en 3,3~V, sans diviseur. \textbf{Vérifier lequel
des deux vous avez avant de câbler} — c'est le verrou le plus coûteux du projet
(voir « Difficultés techniques »).
\end{avertissement}

\begin{note}[Laser : 5~W au calcul, 5,5~W à l'achat]
Le dimensionnement théorique du rapport de soutenance a été conduit pour $P = 5$~W à 460~nm ;
la diode physiquement présente fait \textbf{5,5~W}. Les deux valeurs sont cohérentes en ordre
de grandeur et ne changent aucune conclusion. \textbf{Classe 4 dans les deux cas.}
\end{note}

\paragraph{Moteurs.} GM5208-12, PMSM \emph{pancake} : \textbf{7 paires de pôles}
(14 aimants), $R_s = 7{,}48~\Omega$, $L_s = 4{,}49$~mH, tension nominale 23,6~V, courant
nominal 1,5~A. Encodeur magnétique absolu AS5048A, \textbf{14 bits} $\rightarrow$ résolution
$360/2^{14} \approx 0{,}022^\circ$, borne théorique de précision de la tourelle.

% =====================================================================
\section{Câblage}

Le câblage complet, broche à broche, est en annexe :
\textbf{\fichier{docs/annexes/cablage.md}}. Il n'est pas reproduit ici, mais
\textbf{deux points sont critiques} et doivent être connus avant de souder :

\begin{avertissement}[Les deux pièges du câblage]
\textbf{1. Le potentiomètre \textsc{pan} se câble sur \broche{PB14} — jamais sur
\broche{PA2}, contrairement au brochage nominal du shield.}\\
Sur la NUCLEO-G431RB, \broche{PA2} est câblée sur \texttt{USART2\_TX} — la console série du
ST-LINK. C'est aussi la broche « \textsc{speed} » par défaut du shield IHM16M1 : suivre le
brochage nominal du shield y met donc le potentiomètre, ce qui \textbf{coupe la console} sans
qu'aucun symptôme ne désigne le coupable.

\medskip
\textbf{2. \broche{PA4} est réservée au SPI (NSS matériel), pas au retour de courant.}\\
Elle doit rester haute, sous peine de faire basculer le SPI1 — qui porte les deux encodeurs
— en mode esclave. Le retour de courant de la phase W du moteur 1 est sacrifié en
conséquence.
\end{avertissement}

\paragraph{Bus CAN.} \textbf{Lire d'abord l'avertissement sur les transceivers contrefaits}
(§\ref{sec:bom}) : il détermine la tension d'alimentation du module.
\begin{itemize}[nosep]
  \item Côté Jetson : \texttt{CTX} $\rightarrow$ broche \textbf{31}, \texttt{CRX}
        $\rightarrow$ broche \textbf{29}, GND $\rightarrow$ broche 6. L'alimentation du module
        dépend de son authenticité (3,3~V si véritable, 5~V si clone).
  \item Côté STM32 : \texttt{CAN\_TX} = \broche{PB9}, \texttt{CAN\_RX} = \broche{PB8}.
  \item \textbf{Masse commune obligatoire} entre les n\oe uds (3\ieme{} fil) : le CAN est
        différentiel, mais le transceiver a une limite de tension de mode commun.
        \textbf{Attention au piège de banc} : lorsque les deux cartes sont reliées par USB au
        \emph{même} PC, elles partagent déjà une masse par les blindages. Le bus semble
        fonctionner \emph{sans} fil de masse — et meurt dès qu'on les débranche pour passer
        sur batterie.
  \item Terminaison \textbf{120~$\Omega$} aux \emph{deux extrémités} du bus, et
        \emph{seulement} aux extrémités. Les modules WCMCU-230 embarquent une résistance
        (sérigraphiée \texttt{R2}, marquage « 121 ») : la dessouder sur tout n\oe ud qui
        n'est pas en bout de bus.
\end{itemize}

% =====================================================================
\newpage
\section{Installation du Jetson Orin Nano}

\begin{avertissement}[L'étape la plus délicate du projet]
Le Jetson ne fonctionne \textbf{pas} avec le noyau JetPack standard : les caméras OV9281
exigent le \textbf{noyau Arducam}. Et une fois cette configuration en place, l'outil
\fichier{jetson-io.py} \textbf{ne doit plus jamais être exécuté} — il régénère globalement
les \emph{overlays} d'arbre de périphériques et \textbf{détruit la synchronisation stéréo}.
\end{avertissement}

\subsection{Système de base}

\begin{enumerate}
  \item Flasher le \textbf{JetPack 6.2.1} (L4T r36.4) sur le Jetson Orin Nano Super, via
        NVIDIA SDK Manager. Racine sur NVMe recommandée (c'est la configuration d'origine).
  \item Installer le \textbf{noyau et les pilotes Arducam} pour l'OV9281, en suivant la
        procédure du constructeur. Cela installe un noyau dédié dans
        \fichier{/boot/arducam/}.
\end{enumerate}

\subsection{Overlays d'arbre de périphériques}

La configuration matérielle est portée par trois \emph{overlays} chargés au démarrage. Les
fichiers de référence sont conservés dans \fichier{jetson/} :

\begin{center}
\begin{tabularx}{\textwidth}{@{}p{6.2cm}X@{}}
\toprule
\textbf{Overlay} & \textbf{Rôle} \\
\midrule
\fichier{tegra234-p3767-camera-\newline p3768-arducam-dual.dtbo} &
Double caméra OV9281. C'est lui qui résout le conflit apparent d'adresse
I\textsuperscript{2}C (un bus par port CSI). \\
\addlinespace
\fichier{jetson-io-hdr40-user-custom.dtbo} &
\textbf{PWM de synchronisation} (broches 32 et 33 de l'en-tête 40 points).
\textcolor{vespared}{\textbf{Ne pas modifier ni régénérer.}} \\
\addlinespace
\fichier{can0-pinmux.dtbo} &
\textbf{Routage du CAN0} sur les broches 29/31. \textcolor{vespagreen}{\textbf{Fonctionne}} —
c'est cet \emph{overlay} qui a porté le bus. \textbf{Vérifier après chaque mise à jour qu'il
est toujours dans \fichier{/boot}} (copie de secours : \fichier{jetson/dts/}). \\
\bottomrule
\end{tabularx}
\end{center}

\noindent
Le fichier \fichier{/boot/extlinux/extlinux.conf} de référence est fourni
(\fichier{jetson/extlinux.conf.reference}). L'entrée active y charge le noyau Arducam et
la liste d'\emph{overlays} :

\begin{lstlisting}[language=bash]
LABEL JetsonIO
    MENU LABEL Custom Header Config: <CSI Camera ARDUCAM Dual>
    LINUX /boot/arducam/Image
    FDT   /boot/arducam/dts/dtb/tegra234-p3768-0000+p3767-0005-nv-super.dtb
    INITRD /boot/initrd
    APPEND ${cbootargs} root=PARTUUID=... rw rootwait rootfstype=ext4 ...
    OVERLAYS /boot/arducam/dts/tegra234-p3767-camera-p3768-arducam-dual.dtbo,
             /boot/jetson-io-hdr40-user-custom.dtbo,
             /boot/can0-pinmux.dtbo
\end{lstlisting}

\subsection{Vérifications}

\begin{lstlisting}[language=bash]
# Les deux cameras doivent apparaitre
ls /dev/video*                       # -> /dev/video0  /dev/video1
v4l2-ctl --list-devices

# Le PWM de synchronisation doit etre exportable
ls /sys/class/pwm/pwmchip3/

# Le CAN physique : les broches doivent etre RECLAMEES par le controleur
sudo bash -c "cat /sys/kernel/debug/pinctrl/*/pinmux-pins | grep -i paa"
#   ATTENDU : pin 0 (CAN0_DOUT_PAA0): c310000.mttcan
#   ECHEC   : pin 0 (CAN0_DOUT_PAA0): (MUX UNCLAIMED)  -> overlay absent
\end{lstlisting}

\begin{avertissement}[Après toute mise à jour du Jetson, revérifier ceci]
Une mise à jour de JetPack peut \textbf{supprimer silencieusement}
\fichier{/boot/can0-pinmux.dtbo} sans toucher à la ligne \texttt{OVERLAYS} qui le référence.
Le \emph{bootloader} ne trouve rien, \textbf{n'émet aucune erreur}, et démarre sans
l'\emph{overlay} : \texttt{can0} existe toujours, mais ses broches ne sont plus routées et
le bus est muet. \textbf{C'est exactement ainsi que le bus a été perdu à la fin du projet.}
\begin{lstlisting}[language=bash]
find /boot -name "*can*.dtbo"    # si vide : recopier depuis jetson/dts/
\end{lstlisting}
\end{avertissement}

\subsection{Bus CAN virtuel (pour développer sans matériel)}

\texttt{vcan0} présente à SocketCAN une interface \textbf{indiscernable d'un bus réel} : le
code applicatif est identique. C'est ce qui a permis d'écrire et de valider tout le protocole
avant que le bus physique soit disponible, puis de basculer sur \texttt{can0} sans changer une
ligne. Le fichier \fichier{jetson/systemd/vcan.conf} charge le module au démarrage :

\begin{lstlisting}[language=bash]
sudo modprobe vcan
sudo ip link add dev vcan0 type vcan
sudo ip link set up vcan0
candump vcan0                        # observer les trames
\end{lstlisting}

\noindent
Le service \fichier{jetson/systemd/can0-setup.service} configure le bus \emph{physique}
(500~kbit/s) et ne se déclenche que si le noyau crée réellement le périphérique
\texttt{can0}.

% =====================================================================
\newpage
\section{Compilation}

\subsection{N\oe ud de vision (Jetson)}

\paragraph{Dépendances.}
\begin{lstlisting}[language=bash]
sudo apt install libopencv-dev libi2c-dev libzmq3-dev cppzmq-dev \
                 nlohmann-json3-dev v4l-utils can-utils cmake build-essential
\end{lstlisting}

\begin{note}[CUDA et VPI ne sont plus des prérequis]
Le chemin de code actuel (ArUco + OpenCV) ne dépend \textbf{ni de CUDA, ni de VPI, ni de
TensorRT}. Les \texttt{find\_package(CUDA)} et \texttt{find\_package(VPI 3.0)}, vestiges de
la voie d'inférence abandonnée, ont été \textbf{retirés} du \fichier{CMakeLists.txt} ; ils y
restent en commentaire, à réactiver tels quels si une reprise réintroduit l'inférence sur
GPU. Le test sur \fichier{i2c/smbus.h} est en revanche \textbf{conservé} : les cibles HAL
(\texttt{test\_camera\_hal}, \texttt{test\_hardware\_sync}, \texttt{sparse\_tracker})
lient \texttt{i2c}.
\end{note}

\paragraph{Construction.}
\begin{lstlisting}[language=bash]
cd software/vision_node
mkdir -p build && cd build
cmake .. && make -j6
\end{lstlisting}

\paragraph{Cibles produites.}
\begin{center}
\begin{tabularx}{\textwidth}{@{}lX@{}}
\toprule
\textbf{Binaire} & \textbf{Usage} \\
\midrule
\texttt{vision\_node} & \textbf{Cible de production.} Sans interface, sans ZeroMQ. Émet sur le CAN. \\
\texttt{stereo\_tracker} & Idem + flux ZeroMQ pour la visualisation (\emph{live viewport}). \\
\texttt{calibration\_bridge} & Pont ZeroMQ pour les outils Python de calibration. \\
\texttt{test\_camera\_hal} & Test unitaire d'acquisition. \\
\texttt{test\_hardware\_sync} & \textbf{Test de la synchronisation stéréo} — à lancer en premier. \\
\texttt{test\_stereo\_pipeline} & Test de la triangulation hors ligne. \\
\texttt{sparse\_tracker} & Triangulation par la géométrie stéréo complète (K/D/R/T,
\texttt{cv::triangulatePoints}) — chemin de validation de la voie éparse (voir l'annexe
dette technique). \\
\bottomrule
\end{tabularx}
\end{center}

\paragraph{Exécution.} Les droits \emph{root} sont nécessaires (accès à
\fichier{/sys/class/pwm} et \fichier{/dev/video*}) :
\begin{lstlisting}[language=bash]
sudo ./vision_node
\end{lstlisting}

\subsection{N\oe ud de mouvement (STM32)}

Projet PlatformIO. La bibliothèque commune est liée par lien symbolique, ce qui garantit
qu'il n'existe \textbf{qu'une seule définition} du protocole CAN :

\begin{lstlisting}[language=bash]
cd software/motion_node
pio run                  # compiler
pio run -t upload        # televerser (sonde ST-LINK integree a la Nucleo)
pio device monitor -b 115200
\end{lstlisting}

\noindent
Configuration (\fichier{platformio.ini}) : \texttt{board = nucleo\_g431rb}, framework
Arduino, SimpleFOC 2.3.2, avec activation explicite des modules HAL
\texttt{OPAMP} et \texttt{FDCAN}.

\begin{avertissement}[Ne jamais instancier \texttt{MotionCan} sans arguments]
Le constructeur déclare des valeurs par défaut \texttt{(PA11, PA12)} qui sont
\textbf{fausses} pour ce câblage — \broche{PA11} est le \texttt{EN/FAULT} du moteur~1.
Toujours passer les broches explicitement :
\texttt{MotionCan canBus(CAN\_RX, CAN\_TX);} soit \broche{PB8}/\broche{PB9}.
\end{avertissement}

% =====================================================================
\newpage
\section{Calibration}

Trois outils web (Flask) tournent sur le Jetson et s'utilisent depuis un navigateur
distant — la machine étant sans écran. Ils n'écoutent que sur \texttt{localhost}
(127.0.0.1) : depuis un poste distant, y accéder par un tunnel SSH
(\texttt{ssh -L 5000:localhost:5000 <jetson>}, en adaptant le port — exposition : 5000,
\emph{viewport} : 5001, calibration stéréo : 5002).

\begin{avertissement}[Un seul programme à la fois sur le matériel]
Le n\oe ud de vision et les outils Python se disputent le bus I\textsuperscript{2}C. Un
verrou d'exclusion (\fichier{/tmp/vespa\_hardware.lock}) fait \textbf{échouer volontairement}
le second démarrage. \textbf{Ce n'est pas un bug} : arrêter l'un avant de lancer l'autre.
\end{avertissement}

\subsection{Ordre des opérations}

\begin{enumerate}
  \item \textbf{Exposition et gain} — \fichier{software/tools/calib\_exposition/}
        \begin{lstlisting}[language=bash]
cd software/tools/calib_exposition
./run_exposure.sh                    # http://localhost:5000
        \end{lstlisting}
        Régler l'exposition et le gain jusqu'à obtenir un marqueur net et contrasté.
        Les profils sont enregistrés dans
        \fichier{software/vision\_node/config/profiles/} (\fichier{P1}, \fichier{P2\_dark},
        \fichier{P3\_bright}), le profil actif étant désigné par
        \fichier{config/.active\_profile}.

        \begin{note}[Limite connue]
        Le capteur n'applique pas le même calcul de temps-ligne en mode maître et en mode
        déclenchement externe. \textbf{Les valeurs réglées par cet outil ne correspondent pas
        exactement à celles du \emph{pipeline} C++.} Prévoir un ajustement final en
        conditions réelles.
        \end{note}

  \item \textbf{Calibration stéréo} — \fichier{software/tools/calib\_stereo/}
        \begin{lstlisting}[language=bash]
cd software/tools/calib_stereo
./run_calibration.sh                 # http://localhost:5002
        \end{lstlisting}
        Méthode de Zhang \cite{zhang2000calibration} sur mire d'échiquier.
        \textbf{Couvrir tout le champ} — coins, bords, près et loin, et pas seulement le
        centre : sans couverture des bords, la distorsion ne peut pas être résolue, la
        focale « hallucine » et l'erreur RMS explose. Résultat écrit dans
        \fichier{config/stereovision\_settings.json}.

  \item \textbf{Vérification} — \fichier{software/tools/viewport\_live/}
        \begin{lstlisting}[language=bash]
cd software/tools/viewport_live
./run_liveviewport.sh                # http://localhost:5001
        \end{lstlisting}
        Affiche le flux avec superposition : position courante du marqueur et
        \textbf{visée prédictive} (réticule cyan) issue du filtre de Kalman.
\end{enumerate}

% =====================================================================
\section{Mise en route}

\begin{enumerate}
  \item \textbf{Vérifier la synchronisation} avant toute chose :
        \begin{lstlisting}[language=bash]
sudo ./build/test_hardware_sync
        \end{lstlisting}
        La dérive inter-caméras doit être nulle. Si elle ne l'est pas, ne pas aller plus
        loin : la triangulation serait fausse.

  \item \textbf{Monter le bus} : \texttt{can0} si le matériel est câblé, \texttt{vcan0} pour
        travailler sans, et lancer \texttt{candump} sur une seconde console.

  \item \textbf{Démarrer le n\oe ud de mouvement.} À la mise sous tension, la séquence FOC
        s'initialise. Les décalages d'encodeur sont \textbf{codés en dur} dans
        \fichier{main.cpp} :
        \texttt{motorPan.sensor\_offset = 4{,}7500}, \texttt{motorTilt.sensor\_offset =
        4{,}8179} — ils repoussent le passage $0/2\pi$ hors de la plage utile.
        \textbf{Ils sont propres à un montage mécanique donné} et devront être réétalonnés
        sur un nouveau montage (\fichier{Examples/OneTimeInitialisationAngle.cpp}).

  \item \textbf{Démarrer le n\oe ud de vision} : \texttt{sudo ./vision\_node}.

  \item \textbf{Présenter le marqueur ArUco} dans la \emph{killbox}. La tourelle doit
        suivre.
\end{enumerate}

\paragraph{Butées logicielles} (\fichier{main.cpp}, en radians) — elles protègent la
mécanique et doivent être revues sur un nouveau montage :
\begin{center}
\begin{tabular}{@{}lrr@{}}
\toprule
\textbf{Axe} & \textbf{Min} & \textbf{Max} \\
\midrule
\textsc{pan}  & $-0{,}52$ rad ($-30^\circ$) & $+0{,}52$ rad ($+30^\circ$) \\
\textsc{tilt} & $-0{,}26$ rad ($-15^\circ$) & $+0{,}78$ rad ($+45^\circ$) \\
\bottomrule
\end{tabular}
\end{center}

\paragraph{Arrêt d'urgence.} Bouton bleu (\broche{PC13}). L'arrêt est \textbf{latché} :
coupure des deux étages de puissance, diffusion d'un \emph{heartbeat} \texttt{FAULT}, puis
boucle infinie. \textbf{Seul un reset matériel (bouton noir) permet de repartir.} C'est
délibéré : sur un système portant un laser de Classe 4, aucun redémarrage automatique n'est
acceptable.

% =====================================================================
\newpage
\section{Zone opérationnelle et dimensionnement}

\paragraph{La \emph{killbox}.} Volume dans lequel une cible peut être neutralisée :
parallélépipède de \textbf{500~mm $\times$ 310~mm $\times$ 300~mm}
(longueur $\times$ largeur $\times$ hauteur). La tourelle est placée \textbf{en surplomb},
de sorte que le tir soit dirigé vers le sol.

\begin{figure}[htbp]
  \centering
  
  \caption{La \emph{killbox} : restriction volontaire de l'environnement. Le système
  n'engage une cible que dans ce volume, ce qui borne à la fois la portée du tir et le
  domaine où la précision de pointage a été caractérisée.}
  \label{fig:killbox}
\end{figure}

\paragraph{Optique.} Le compromis porte sur le GSD (\emph{Ground Sampling Distance}) : il ne
doit pas dépasser $\approx 0{,}5$~mm/px pour rester exploitable par un modèle de détection.
Pour un capteur $1\,280 \times 800$, le script
\fichier{simulation/vision/Camera\_PosResAttitude\_v6.m} donne :
\[
  f = 6~\text{mm}, \qquad d_n = 990~\text{mm}
\]

\paragraph{Chemin optique du tir.} Le faisceau de la diode est collimaté par \textbf{L1}
(lentille fixe), puis focalisé par \textbf{L2} (\textbf{lentille mobile}) sur la cible. C'est
le déplacement de L2 le long de l'axe qui réalise la \textbf{collimation dynamique} :
il déplace le point de focalisation avec la distance de la cible, de manière à concentrer la
puissance sur la cible et \emph{seulement} sur elle. La loi de commande $x_{L2} = f(x_c)$ est
établie dans \fichier{simulation/optique/Laser\_Optics\_v1.m} ; le mécanisme est spécifié mais
\textcolor{vespared}{\textbf{n'a jamais été assemblé ni étalonné}} (il relève du n\oe ud de
coordination, non implémenté).

\begin{figure}[htbp]
  \centering
  \begin{tikzpicture}[x=1cm,y=1cm,>=latex,font=\small]
    % --- axe optique ---
    \draw[dashed,gray] (-0.4,0) -- (13.2,0);

    % --- source ---
    \fill (0,0) circle (2pt);
    \node[above=3pt] at (0,0) {\footnotesize source};

    % --- L1 (fixe) ---
    \draw[very thick,<->] (2,-1.1) -- (2,1.1);
    \node[above] at (2,1.1) {\textbf{L1}};
    \node[below] at (2,-1.1) {\footnotesize fixe};

    % --- L2 (mobile) ---
    \draw[very thick,<->] (5,-1.7) -- (5,1.7);
    \node[above] at (5,1.7) {\textbf{L2}};
    \node[below,align=center] at (5,-1.7) {\footnotesize mobile\\[-2pt]\footnotesize (collimation)};
    \draw[->,thick,vespared] (4.45,2.15) -- (5.55,2.15);
    \draw[->,thick,vespared] (5.55,2.35) -- (4.45,2.35);

    % --- faisceau : source -> L1 (divergent) ---
    \draw (0,0) -- (2,0.62);   \draw (0,0) -- (2,-0.62);
    % --- L1 -> L2 (collimate, elargi) ---
    \draw (2,0.62) -- (5,1.25);  \draw (2,-0.62) -- (5,-1.25);
    % --- L2 -> cible (convergent) ---
    \draw (5,1.25) -- (12,0);   \draw (5,-1.25) -- (12,0);
    % --- au-dela de la cible : divergence ---
    \draw[gray] (12,0) -- (13.2,0.42);  \draw[gray] (12,0) -- (13.2,-0.42);

    % --- diametre en L2 ---
    \draw[<->] (5.5,-1.25) -- (5.5,1.25)
      node[midway,fill=white,inner sep=1.5pt] {$\varnothing_2$};

    % --- cible ---
    \node[vespared] at (12,0) {\Large $\boldsymbol{\times}$};
    \node[below=6pt,vespared] at (12,0) {\textbf{cible}};

    % --- cotes ---
    \draw[|<->|,gray] (0,-2.5) -- (2,-2.5) node[midway,below] {$x_{L1}$};
    \draw[|<->|,gray] (2,-2.5) -- (5,-2.5) node[midway,below] {$x_{L2}$};
    \draw[|<->|,gray] (5,-2.5) -- (12,-2.5) node[midway,below] {$x_c$ (distance cible)};
  \end{tikzpicture}
  \caption{Chemin optique du tir. L1 collimate le faisceau de la diode ; \textbf{L2, mobile},
  le focalise sur la cible. Déplacer L2 déplace le point de focalisation : c'est le principe
  de la collimation dynamique. Hors du plan de focalisation, la densité de puissance chute —
  \textbf{mais pas assez vite pour supprimer le risque oculaire} (voir « Difficultés
  techniques », profondeur de champ létale, et \fichier{docs/annexes/securite\_laser.md}).}
  \label{fig:optic-path}
\end{figure}

\paragraph{Cadence.} La boucle complète doit tenir dans \textbf{16,6~ms} (60~Hz). À 60~fps,
le système suit une cible se déplaçant jusqu'à $0{,}6~\text{m}\cdot\text{s}^{-1}$ — ce qui
suppose un \textbf{frelon en vol de guet quasi stationnaire}, comportement effectivement
documenté devant les ruches \cite{perrard2009colonie}. Un frelon en vol rapide
($\approx 6~\text{m}\cdot\text{s}^{-1}$) exigerait 600~fps : \textbf{hors de portée}, et
c'est une limite assumée du système.

\paragraph{Obturateur global : pourquoi il est non négociable.} Le flou de mouvement vaut
$b = v \cdot t_{\text{exp}} / R$. À $0{,}6~\text{m}\cdot\text{s}^{-1}$, avec 2~ms
d'exposition et $R = 0{,}5$~mm/px, on obtient $b = 2$~px — sur une cible qui n'en mesure que
20 à 35. Un obturateur à balayage (\emph{rolling shutter}) est donc éliminé. Or aucun
capteur \textbf{trichrome} à obturateur global n'existe à prix abordable : \textbf{d'où le
capteur monochrome, et d'où l'incompatibilité avec VespAI}
(voir « Difficultés techniques »).

% =====================================================================
\section{Structure du dépôt}

\begin{lstlisting}
project_vespa/
|- docs/                  Rapports (PDF + sources LaTeX), annexes, references
|  |- src/                Sources LaTeX + vespa.bib + figures (figs/)
|  |- annexes/            Cablage, protocole CAN, BOM, setup Jetson,
|  |                      securite, dette technique
|  \- references/         Articles, datasheets, etudes preparatoires (IA)
|- hardware/
|  \- mechanical/         CAO (STEP), maillages imprimes, plateaux, moteur
|- jetson/                Config systeme (overlays, services CAN, extlinux)
|- simulation/            Scripts MATLAB de dimensionnement (vision + optique)
\- software/
   |- common/             Protocole CAN partage (C - STM32/ESP32/Linux)
   |- vision_node/        Jetson - C++17 / OpenCV / V4L2 / SocketCAN (CMake)
   |- motion_node/        STM32G431RB - SimpleFOC / FDCAN (PlatformIO)
   |- coordination_node/  ESP32 - NON IMPLEMENTE (specification seule)
   |- tools/              Calibration stereo, exposition, viewport
   \- legacy_mk1_bench/   Banc de caracterisation mk.1 (Arduino Uno)
\end{lstlisting}

\paragraph{Le banc mk.1.} \fichier{software/legacy\_mk1\_bench/} contient le code Arduino
ayant servi à caractériser le prototype de première génération (comparaison des algorithmes
« classique » et « accumulateur », mesure du \emph{jitter}, test d'endurance). Ce sont les
\textbf{annexes A à D du rapport de soutenance}. Il est conservé parce qu'il porte les
mesures qui justifient l'abandon des moteurs pas-à-pas.

% =====================================================================
\section{Synthèse de l'état livré}

\begin{center}
\begin{tabularx}{\textwidth}{@{}lXl@{}}
\toprule
\textbf{Sous-système} & \textbf{État} & \textbf{Validé sur} \\
\midrule
Acquisition stéréo & Synchronisation matérielle 60~Hz, dérive 0,000~ms &
\textcolor{vespagreen}{matériel réel} \\
Triangulation & Stéréo éparse sur marqueur ArUco &
\textcolor{vespagreen}{matériel réel} \\
Prédiction & Filtre de Kalman, compense la latence de la chaîne &
\textcolor{vespagreen}{matériel réel} \\
Asservissement & FOC boucle fermée, 2 axes, butées, arrêt d'urgence &
\textcolor{vespagreen}{matériel réel} \\
Protocole CAN & Sérialisation, priorités, \emph{heartbeats} &
\textcolor{vespagreen}{matériel réel} \\
Bus CAN physique & Jetson $\leftarrow$ STM32 : \textbf{111\,909 trames, 0 erreur} &
\textcolor{vespagreen}{matériel réel} \\
\midrule
\textbf{Bus CAN — sens émission} & \textcolor{vespaaccent}{\textbf{Non reconfirmé}} après
correction des transceivers contrefaits & — \\
\textbf{Bus CAN — persistance} & \textcolor{vespaaccent}{\textbf{Fragile}} —
l'\emph{overlay} est dans \fichier{/boot} (copie : \fichier{jetson/dts/}), mais une mise à
jour JetPack peut l'effacer sans erreur ; à revérifier après chaque mise à jour & — \\
\textbf{Détection du frelon} & \textcolor{vespared}{\textbf{Absente}} — remplacée par ArUco
& — \\
\textbf{Watchdog} & \textcolor{vespared}{\textbf{Non implémenté}} & — \\
\textbf{Tir laser} & \textcolor{vespared}{\textbf{Jamais effectué}} (décision de sécurité)
& — \\
\bottomrule
\end{tabularx}
\end{center}

\begin{avertissement}[Avant toute mise sous tension du laser]
Le laser est de \textbf{Classe 4}. Il n'a jamais été alimenté, faute de watchdog. Lire
\fichier{docs/annexes/securite\_laser.md} \textbf{en entier} avant d'y toucher. La
collimation dynamique réduit le risque d'incendie, \textbf{pas} le risque oculaire, qui
persiste sur près de 200~m.
\end{avertissement}

% =====================================================================
\newpage
\bibliographystyle{plain}
\bibliography{vespa}

\end{document}

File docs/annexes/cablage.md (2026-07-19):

# Annexe — Câblage du `motion_node`

Matériel : 1× **NUCLEO-G431RB**, 2× **X-NUCLEO-IHM16M1** (STSPIN830), 2× encodeurs
**AS5048A**, 1× transceiver CAN **WCMCU-230**.
Les deux shields sont montés **côte à côte** (et non empilés), cavaliers configurés pour
la FOC à **3 shunts**.

> **Source unique de vérité : [`software/motion_node/include/pinout.h`](../../software/motion_node/src/../include/pinout.h).**
> Le firmware ne lit que ce fichier. Le tableau ci-dessous en est le reflet.

---

## ⚠️ Deux pièges à connaître avant de câbler

Ces deux points ne sont pas des erreurs de conception : ce sont des contraintes de la carte
Nucleo, et elles ont coûté du temps.

### 1. Le potentiomètre PAN n'est **pas** sur `PA2` — il est sur `PB14`

`PA2` est le brochage par défaut du shield IHM16M1 pour l'entrée « SPEED »
(potentiomètre). Mais sur la NUCLEO-G431RB, **`PA2` est câblée sur `USART2_TX`, la liaison
série virtuelle du ST-LINK** (le port COM que l'on ouvre pour lire la console).

Suivre le brochage nominal du shield revient donc à court-circuiter la sortie série : la
console devient muette ou crache des caractères parasites, sans qu'aucun symptôme ne pointe
vers le potentiomètre. Le potentiomètre PAN est donc sur **`PB14`**.

### 2. `PA4` ne fait pas de retour de courant — il protège le SPI

`PA4` est à la fois la broche `SENSEW` du moteur 1 (retour de courant phase W) *et* la
broche **NSS matérielle du SPI1**. Le bus SPI1 porte les deux encodeurs AS5048A, dont
dépend tout l'asservissement. Un NSS matériel laissé flottant peut faire basculer le
périphérique SPI en mode esclave et tuer la lecture des encodeurs.

`PA4` est donc **maintenue haute et réservée au SPI**. Conséquence assumée : le retour de
courant de la phase W du moteur 1 est sacrifié. Le FOC fonctionne (SimpleFOC reconstruit
la 3ᵉ phase : `iW = -iU - iV`), mais **la mesure de courant n'est pas activée dans le
firmware actuel** — l'asservissement est en position/vitesse sur encodeur seul.

---

## 1. Alimentation et masses

Le 24 V moteur est **isolé** de la logique 3,3 V. Les masses sont communes.

| Signal | NUCLEO-G431RB | Shield 1 (M1) | Shield 2 (M2) |
|---|---|---|---|
| 24 V puissance | — | CN1 pin 2 (VIN) | CN1 pin 2 (VIN) |
| Masse puissance | — | CN1 pin 1 (GND) | CN1 pin 1 (GND) |
| Logique 3,3 V | 3V3 | CN7 pin 12 | CN7 pin 12 |
| Masse logique | GND | CN7 pin 20 | CN7 pin 20 |

## 2. Moteur 1 — PAN (TIM1 / ADC1, brochage par défaut du shield)

| Signal | MCU | Shield | Morpho |
|---|---|---|---|
| Commande INU | `PA8` | INU | CN10-23 |
| Commande INV | `PA9` | INV | CN10-21 |
| Commande INW | `PA10` | INW | CN10-33 |
| EN / FAULT | `PA11` | EN\FAULT | CN10-14 |
| Courant U | `PA1` | SENSEU | CN7-30 |
| Courant V | `PB1` | SENSEV | CN10-24 |
| Courant W | ~~`PA4`~~ | SENSEW | *(réservé SPI1-NSS — voir piège n°2)* |
| Tension bus | `PA0` | VBUS | CN7-28 |
| **Potentiomètre** | **`PB14`** | SPEED | *(déplacé — voir piège n°1)* |

## 3. Moteur 2 — TILT (TIM8 / ADC2, routage MCU personnalisé)

Le second shield ne peut pas réutiliser le brochage par défaut : il est remappé sur
un second timer avancé (TIM8) et un second ADC.

| Signal | MCU | Shield | Morpho |
|---|---|---|---|
| Commande INU | `PC6` | INU | CN10-23 |
| Commande INV | `PC7` | INV | CN10-21 |
| Commande INW | `PC8` | INW | CN10-33 |
| EN / FAULT | `PB12` | EN\FAULT | CN10-14 |
| Courant U | `PC0` | SENSEU | CN7-30 |
| Courant V | `PC1` | SENSEV | CN10-24 |
| Courant W | `PC2` | SENSEW | CN7-34 |
| Tension bus | `PC3` | VBUS | CN7-28 |
| Potentiomètre | `PB0` | SPEED | CN7-35 |

## 4. Encodeurs AS5048A — SPI1 (bus partagé, 2 chip-selects)

Bus SPI commun aux deux encodeurs ; seule la ligne CS les distingue.

| Signal | MCU | AS5048A (M1) | AS5048A (M2) | Fil |
|---|---|---|---|---|
| Masse | CN7-20 | GND | GND | blanc |
| 3,3 V | CN7-16 | VCC | VCC | rouge |
| MISO | `PA6` | MISO | MISO | vert |
| MOSI | `PA7` | MOSI | MOSI | jaune |
| SCK | `PA5` | SCK | SCK | bleu |
| CS pan | `PB6` | CS | — | noir |
| CS tilt | `PB7` | — | CS | noir |
| *(NSS matériel)* | `PA4` | *maintenu haut* | | |

## 5. Transceiver CAN WCMCU-230 — FDCAN1

| Signal | MCU | WCMCU-230 |
|---|---|---|
| 3,3 V | CN7-16 | 3V3 |
| Masse | CN7-20 | GND |
| CAN TX | `PB9` (CN10-5) | CTX / TX |
| CAN RX | `PB8` (CN10-3) | CRX / RX |
| CAN High | — | CANH → bus |
| CAN Low | — | CANL → bus |

> ⚠️ **L'alimentation 3,3 V du tableau vaut pour un véritable SN65HVD230.** Les modules
> du lot du projet sont des **contrefaçons 5 V** (voir [`bom.md`](bom.md)) : leur remontage
> passe par le correctif 5 V décrit dans *Difficultés techniques*. Vérifier ce que vous avez
> en main avant de câbler.

> ⚠️ **Attention au piège du constructeur `MotionCan`.** Sa signature déclare des valeurs
> par défaut `MotionCan(rxPin = PA11, txPin = PA12)` — qui sont **fausses** pour ce
> câblage (`PA11` est le EN/FAULT du moteur 1 !). Le firmware passe toujours les broches
> explicitement : `MotionCan canBus(CAN_RX, CAN_TX);` → `PB8`/`PB9`.
> **Ne jamais instancier `MotionCan` sans arguments.**

## 6. Sécurité

| Fonction | Broche |
|---|---|
| Arrêt d'urgence matériel (bouton bleu) | `PC13` |

L'arrêt d'urgence est **latché** : l'ISR coupe les deux étages de puissance
(`EN/FAULT` → bas), diffuse un *heartbeat* `FAULT` (`0x02`) sur le CAN, puis entre dans une
boucle infinie. **Seul un reset matériel (bouton noir) permet de repartir.** C'est
volontaire : sur un système portant un laser de Classe 4, aucun redémarrage automatique
n'est acceptable.

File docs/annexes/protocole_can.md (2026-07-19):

# Annexe — Protocole CAN du projet VESPA

> **Source unique de vérité : [`software/common/can_protocol.h`](../../software/common/can_protocol.h).**
> Ce document décrit le protocole ; le header le *définit*. En cas de divergence,
> le header fait foi. Toute modification du protocole doit être faite dans
> `software/common/`, jamais dupliquée dans un nœud.

## 1. Couche physique

| Paramètre | Valeur |
|---|---|
| Standard | CAN 2.0B (ISO 11898-1), trames **standard 11 bits** |
| Débit | **500 kbit/s** |
| Terminaison | 120 Ω à chaque extrémité du bus |
| Transceiver `motion_node` | WCMCU-230 — ⚠️ **contrefaçon 5 V**, voir [`bom.md`](bom.md) |
| Transceiver `vision_node` | Jetson Orin Nano — contrôleur CAN intégré (MTTCAN), broches 29/31 |

> **Le protocole a tourné sur le bus physique** : le Jetson a reçu **111 909 trames du
> STM32, sans une seule erreur** (relevé `ip -s link show can0`, 21 mars 2026). Il a d'abord
> été développé sur interface virtuelle `vcan0`, et le passage au `can0` réel n'a demandé
> **aucune modification du code applicatif**.
>
> Deux points restent à refermer côté matériel — le sens émission, et la persistance de
> l'*overlay* de *pinmux* après redémarrage. Voir *Difficultés techniques*, verrou « bus CAN
> physique », et [`jetson_setup.md`](jetson_setup.md).

## 2. Principe de conception

Deux décisions structurent le protocole :

**Priorité par l'identifiant.** L'arbitrage bit à bit du CAN est non destructif : à
collision, la trame d'identifiant le plus faible gagne le bus sans retransmission. Les
identifiants sont donc attribués par criticité décroissante — `FIRE_CMD` (`0x010`) est
la trame la plus prioritaire du système, les trames de débogage (`0x200`+) les moins
prioritaires.

**Virgule fixe, pas de flottant.** Les angles sont transmis en `int16_t` après
multiplication par `ANGLE_SCALE_FACTOR = 10000`. Cela évite toute sérialisation de
`float` (représentation non garantie entre STM32, ESP32 et aarch64) et supprime le coût
de conversion. Résolution : 10⁻⁴ rad ≈ 0,0057° — bien en deçà de la précision mécanique
(0,022°), donc non limitante.

```c
// Émission                          // Réception
int16_t tx = (int16_t)(rad * 10000.0f);   float rad = rx / 10000.0f;
```

## 3. Dictionnaire de données

| ID | Trame | Émetteur | Récepteur(s) | DLC | Charge utile |
|---|---|---|---|---|---|
| `0x010` | `FIRE_CMD` | vision | coord | 1 | `uint8_t fire_order` — `0x01` = tir, `0x00` = maintien |
| `0x020` | `TARGET_VEC` | vision | motion | 7 | `int16 pan`, `int16 tilt` (×10⁴ rad), `uint16 depth_mm`, `uint8 is_locked` |
| `0x030` | `POS_MOTION` | motion | vision | 4 | `int16 current_pan`, `int16 current_tilt` (×10⁴ rad) |
| `0x040` | `POS_COORD` | coord | vision | 4 | `int32 position_mm` — position linéaire du collimateur |
| `0x100` | `HB_VISION` | vision | coord | 1 | `uint8 system_state` |
| `0x110` | `HB_MOTION` | motion | coord | 1 | `uint8 system_state` |
| `0x120` | `HB_COORD` | coord | coord | 1 | `uint8 system_state` |
| `0x200` | `DBG_MOTION` | motion | broadcast | — | Trame de débogage |
| `0x210` | `DBG_COORD` | coord | broadcast | — | Trame de débogage |

**Codes d'état (`system_state`)** — communs à tous les *heartbeats* :

| Code | Signification |
|---|---|
| `0x00` | `OK` — nominal |
| `0x01` | `WARNING` — dégradé, opération poursuivie |
| `0x02` | `FAULT` — défaut ; le watchdog doit couper l'alimentation |

**Cadences.** `POS_MOTION` : 20 Hz (50 ms). `HB_*` : 1 Hz. `TARGET_VEC` : cadence caméra
(60 Hz nominal). Les cadences du `motion_node` (`POS_MOTION`, `HB_MOTION`) sont fixées dans
`software/motion_node/src/main.cpp` ; `TARGET_VEC` et `HB_VISION` sont émises par le
`vision_node` (`software/vision_node/src/main.cpp`).

## 4. Structures (extrait de `can_protocol.h`)

Toutes les structures sont `__attribute__((packed))` : **aucun bourrage**, sinon la
disposition mémoire diffère entre STM32 (Cortex-M4) et aarch64 et les trames sont
décodées de travers.

```c
typedef struct {
    int16_t  pan_angle;   // rad × 10000
    int16_t  tilt_angle;  // rad × 10000
    uint16_t depth_mm;    // mm
    uint8_t  is_locked;   // 1 = verrouillé
} CAN_PACKED TargetPayload_t;      // 7 octets
```

## 5. Implémentations

| Nœud | Fichier | Pile |
|---|---|---|
| `vision_node` | `software/vision_node/src/vision_can.cpp` | SocketCAN (`PF_CAN`/`SOCK_RAW`) |
| `motion_node` | `software/motion_node/src/motion_can.cpp` | FDCAN1 en mode CAN 2.0 classique |
| commun | `software/common/can_utils.c` | Encodage/décodage, partagé par les deux |

Le nœud de coordination (`coordination_node`, ESP32) **n'est pas implémenté** : ses
trames (`FIRE_CMD` en réception, `POS_COORD`, `HB_COORD`) sont spécifiées ci-dessus mais
aucun code ne les émet ni ne les consomme.

## 6. Vérification sans matériel

Le protocole se teste intégralement sur un bus virtuel, sans aucun câblage :

```bash
sudo modprobe vcan
sudo ip link add dev vcan0 type vcan && sudo ip link set up vcan0
candump vcan0 &                    # observer
# lancer vision_node configuré sur vcan0 : les trames 020 / 010 doivent apparaître
```

`vcan0` est indiscernable d'un bus réel du point de vue de SocketCAN : c'est ainsi que la
sérialisation a été mise au point avant que le matériel soit prêt, puis reportée sur `can0`
sans changer une ligne.

## 7. Diagnostic sur bus physique

Les compteurs du noyau sont l'outil de diagnostic le plus utile du projet — c'est leur
lecture qui a révélé la contrefaçon des transceivers :

```bash
ip -details -statistics link show can0
```

| Ce que vous voyez | Ce que cela signifie |
|---|---|
| `RX` progresse, `TX` figé, état `BUS-OFF` | Vous **recevez** mais n'**émettez** pas. Bus asymétrique ⇒ **couche physique**, pas logiciel. C'était la contrefaçon. |
| `RX` et `TX` à 0, état `ERROR-ACTIVE` | Les broches ne sont probablement pas routées. Vérifier le *pinmux* (`grep -i paa`). |
| `RX errors` grimpe | Signal dégradé : fronts trop lents (convertisseur de niveau ?) ou terminaison absente. |

> **Un bus CAN différentiel ne peut pas être asymétrique.** Si un sens marche et pas
> l'autre, le défaut est électrique, entre le contrôleur et le fil.

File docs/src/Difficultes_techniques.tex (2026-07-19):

\documentclass[11pt,a4paper]{article}
\usepackage{vespa_style}

\begin{document}

\vespatitlepage
  {Difficultés techniques}
  {Verrous levés et verrous reportés}
  {Document de clôture — juillet 2026\\
   Rédigé rétrospectivement à partir du code, des archives de conversation,\\
   des fichiers de configuration du Jetson et des relevés de banc.}

\tableofcontents
\newpage

% =====================================================================
\section{Comment lire ce document}

Ce document recense les obstacles \textbf{non triviaux} rencontrés au cours du projet
\vespa{} — ceux dont la solution n'était ni évidente ni documentée, et ceux qui n'ont pas
été résolus.

Il ne s'agit pas d'un journal de bord. Un bug de compilation n'y figure pas ; un bug qui a
coûté une semaine, faussé une mesure ou contraint une décision d'architecture, oui.

\begin{note}[Convention]
\textbf{\textcolor{vespagreen}{LEVÉ}} — le verrou a été franchi. La cause racine et le
correctif sont donnés, et le correctif est dans le dépôt.

\textbf{\textcolor{vespared}{REPORTÉ}} — le verrou est ouvert. L'état exact des tentatives
est donné, ainsi que la piste jugée la plus prometteuse. \textbf{C'est là que doit
commencer toute reprise du projet.}
\end{note}

\begin{avertissement}[À lire avant de reprendre le matériel]
Plusieurs de ces verrous ne sont \emph{pas visibles dans le code}. Ils sont dans le
silicium, dans le brochage de la carte, ou dans un fichier de configuration du noyau.
Un repreneur qui lirait uniquement les sources rencontrerait à nouveau, une par une,
les mêmes impasses. C'est précisément la raison d'être de ce document.
\end{avertissement}

Une remarque transverse, et elle est structurante. Ce projet a été développé avec une
assistance forte de modèles de langage. Cette assistance a été décisive sur le volume de
code produit. Mais \textbf{sur les verrous matériels, elle a été prise en défaut de manière
répétée}, avec une grande assurance de façade. Les erreurs de diagnostic les plus coûteuses
du projet sont des hypothèses d'IA plausibles, bien argumentées, et fausses — qui n'ont été
écartées que par la mesure. La section~\ref{sec:ia} en fait le bilan explicite, car c'est
une leçon de méthode réutilisable.

% =====================================================================
\newpage
\section{Verrous levés}

% ---------------------------------------------------------------------
\subsection{Faire cohabiter deux caméras MIPI à adresse I\textsuperscript{2}C identique}

\begin{verroulevé}{Double flux OV9281 simultané}
\textbf{Symptôme.} Les deux modules Arducam OV9281 portent la \emph{même} adresse
I\textsuperscript{2}C, figée en dur dans le silicium du capteur. La documentation
courante conclut qu'un multiplexeur I\textsuperscript{2}C matériel est nécessaire pour en
exploiter deux simultanément.

\textbf{Cause racine.} L'adresse est bien unique par capteur, mais les deux caméras ne
partagent pas le même bus : chaque port CSI du Jetson dispose de son propre bus
I\textsuperscript{2}C. Le conflit d'adresse est donc \emph{apparent}, pas réel — à
condition que le noyau instancie bien un sous-périphérique par port.

\textbf{Correctif.} Noyau Arducam personnalisé + \emph{overlay} d'arbre de périphériques
dédié au mode double :
\fichier{tegra234-p3767-camera-p3768-arducam-dual.dtbo}, chargé au démarrage
(voir \fichier{jetson/extlinux.conf.reference}). Les deux capteurs apparaissent alors comme
deux n\oe uds \fichier{/dev/video*} indépendants, chacun avec son propre sous-périphérique
de contrôle. Aucun multiplexeur matériel n'est nécessaire.
\end{verroulevé}

C'est le résultat que le rapport de soutenance qualifiait d'« inédit », et la formulation est
justifiée : la documentation constructeur comme les fils de support concluent à la nécessité
d'un multiplexeur matériel. Le blocage est réputé rédhibitoire ; il ne l'est pas. La solution
économise un composant et une source de latence.

% ---------------------------------------------------------------------
\subsection{Synchroniser les deux capteurs à quelques microsecondes près}

\begin{verroulevé}{Déclenchement matériel commun par PWM du Tegra}
\textbf{Symptôme.} La triangulation stéréo est fausse dès que les deux images ne sont pas
prises au même instant. Sur une cible mobile, un déphasage de quelques millisecondes
suffit à déplacer le point 3D reconstruit de plusieurs centimètres. Or Linux n'est pas un
RTOS : un déclenchement logiciel des deux caméras est soumis à l'ordonnanceur et dérive.

\textbf{Cause racine.} Toute synchronisation pilotée par le CPU est structurellement
inadéquate. Il faut sortir la génération d'horloge du domaine logiciel.

\textbf{Correctif.} Les \textbf{deux} caméras sont forcées en mode esclave
(\fichier{trigger\_mode=1}) et reçoivent le \emph{même} front de déclenchement, généré par
le \textbf{PWM matériel du Tegra} — indépendant de la charge CPU :

\begin{lstlisting}[language=bash]
/sys/class/pwm/pwmchip3/pwm0/period     = 16666666  ns  -> 60 Hz
/sys/class/pwm/pwmchip3/pwm0/duty_cycle =  1666666  ns  -> 10 %
\end{lstlisting}

La simultanéité est ainsi vraie \emph{par construction} : les deux capteurs exposent sur le
même front électrique. Implémentation : \fichier{HardwareSyncController.cpp}
(\texttt{armTrigger}, \texttt{forceSlaveMode}).

\textbf{Résultat mesuré.} Dérive inter-caméras de \textbf{0,000 ms}. Un garde-fou logiciel
subsiste dans \texttt{captureSynchronizedPair()} : toute paire dont les horodatages
s'écartent de plus de 5~ms est rejetée et resynchronisée par consommation de la file la
plus en retard.
\end{verroulevé}

\paragraph{Pourquoi ce résultat est réellement inédit.} Ce n'est pas une figure de style. La
position du constructeur est explicite : la synchronisation matérielle de plusieurs caméras
passe par un accessoire propriétaire, le \textbf{Camarray HAT} (déclinaisons
\emph{Stereoscopic} et \emph{Quadrascopic}), qui agrège les modules et leur injecte une
horloge maîtresse par la nappe~\cite{arducam_uc788}. Les cartes UC-788 vendues dans ces kits
subissent d'ailleurs des modifications d'usine irréversibles (oscillateur 24~MHz non peuplé,
adresse I\textsuperscript{2}C altérée au niveau des résistances) qui les rendent inutilisables
seules. Sur une carte UC-788 \emph{standard}, la piste qui relie la broche \texttt{XVS/FSIN}
du capteur aux pastilles de déclenchement est \textbf{physiquement coupée en sortie
d'usine} — un emplacement 0402 laissé vide fait office de circuit ouvert.

\medskip
\noindent
Autrement dit : le chemin officiel pour obtenir un déclenchement stéréo matériel est
d'\textbf{acheter la carte du constructeur}. Le \emph{vision node} de VESPA ne l'a pas fait.
Il obtient le même résultat sur \textbf{deux cartes UC-788 standard}, en prenant l'horloge
maîtresse là où personne ne la cherche : le \textbf{générateur PWM matériel du Tegra
lui-même}, câblé sur l'en-tête 40 broches. Aucun accessoire, aucun microcontrôleur
intermédiaire, aucune dérive logicielle. \textbf{Le constructeur affirme que cela demande son
matériel ; la mesure dit le contraire.}

% ---------------------------------------------------------------------
\subsection{Les réglages optiques ne s'appliquaient pas}

\begin{verroulevé}{Fenêtre d'application des contrôles V4L2}
\textbf{Symptôme.} Les réglages d'exposition et de gain écrits dans le JSON étaient
silencieusement ignorés par le capteur. Aucune erreur, aucun code de retour :
simplement, l'image ne changeait pas.

\textbf{Cause racine — double.}
\begin{enumerate}[nosep]
  \item \textbf{Fenêtre temporelle.} Les registres actifs du capteur ne « écoutent » pas
        tant que ses PLL ne sont pas stabilisées. Pousser les réglages avant que le flux
        ne tourne revient à écrire dans le vide.
  \item \textbf{Nom de contrôle.} Le pilote V4L2 attend strictement
        \fichier{analogue\_gain} (orthographe britannique). Toute variante
        (\fichier{gain}, \fichier{analog\_gain}) échoue \emph{en silence}. L'exposition
        fonctionnait, le gain non — ce qui rendait le diagnostic contre-intuitif.
\end{enumerate}

\textbf{Correctif.} Séquence d'initialisation stricte dans \texttt{initializeRig()} :
démarrer les flux $\rightarrow$ \textbf{attendre 500~ms} $\rightarrow$ charger le JSON
$\rightarrow$ appliquer $\rightarrow$ forcer le mode esclave $\rightarrow$ purger les files.
Le ticket de dette technique correspondant est \textbf{clos}.
\end{verroulevé}

% ---------------------------------------------------------------------
\subsection{La console série se taisait dès que le potentiomètre était branché}

\begin{verroulevé}{Conflit \broche{PA2} — potentiomètre \emph{vs} USART2\_TX}
\textbf{Symptôme.} Sur le \fichier{motion\_node}, brancher le potentiomètre de réglage fin
de l'axe \textsc{pan} rendait la console série muette ou illisible. Aucun lien apparent
entre les deux.

\textbf{Cause racine.} Le shield X-NUCLEO-IHM16M1 câble son entrée « SPEED »
(potentiomètre) sur \broche{PA2}. Mais sur la carte NUCLEO-G431RB, \broche{PA2} est
\textbf{déjà câblée sur \texttt{USART2\_TX}}, c'est-à-dire sur le port COM virtuel du
ST-LINK. Y injecter une tension analogique revient à court-circuiter la sortie série.

\textbf{Correctif.} Potentiomètre \textsc{pan} déplacé sur \broche{PB14}
(\fichier{pinout.h}). Le câblage de référence est \fichier{docs/annexes/cablage.md} ;
le manifeste de câblage d'origine, qui indiquait encore \broche{PA2}, a été retiré du
dépôt à la clôture du projet.
\end{verroulevé}

% ---------------------------------------------------------------------
\subsection{Le SPI des encodeurs pouvait mourir sans raison}

\begin{verroulevé}{\broche{PA4} : NSS matériel \emph{vs} retour de courant}
\textbf{Cause racine.} \broche{PA4} est simultanément la broche \texttt{SENSEW} du moteur 1
(retour de courant phase W) et le \textbf{NSS matériel du SPI1}. Or SPI1 porte les deux
encodeurs AS5048A, dont dépend tout l'asservissement. Un NSS matériel laissé flottant peut
faire basculer le périphérique SPI en mode esclave et interrompre la lecture des encodeurs.

\textbf{Correctif — un arbitrage, pas une solution.} \broche{PA4} est maintenue haute et
réservée au SPI. \textbf{Le retour de courant de la phase W du moteur 1 est sacrifié.}
C'est acceptable ici : la FOC de SimpleFOC reconstruit la phase manquante
($i_W = -i_U - i_V$), et surtout l'asservissement actuel est en position sur encodeur, sans
boucle de courant. \textbf{Un repreneur qui voudrait activer la mesure de courant devra
rouvrir cet arbitrage.}
\end{verroulevé}

% ---------------------------------------------------------------------
\subsection{Deux programmes se disputaient le bus I\textsuperscript{2}C}

\begin{verroulevé}{Verrou d'exclusion mutuelle matériel}
\textbf{Symptôme.} Lancer un outil Python de calibration pendant que le n\oe ud C++ tournait
corrompait les réglages du capteur, voire figeait le flux.

\textbf{Cause racine.} Les deux processus écrivent sur les mêmes sous-périphériques
I\textsuperscript{2}C. Rien, au niveau du système, ne les en empêche.

\textbf{Correctif.} Verrou exclusif \texttt{flock} sur \fichier{/tmp/vespa\_hardware.lock},
pris au démarrage de \texttt{HardwareSyncController} (\texttt{acquireHardwareLock()}).
Le second processus \textbf{refuse de démarrer} avec un message explicite.

\textbf{Ce n'est pas un bug :} lancer le n\oe ud de vision et un outil Python simultanément
échoue \emph{volontairement}.
\end{verroulevé}

% ---------------------------------------------------------------------
\subsection{\texttt{jetson-io.py} détruisait la configuration des caméras}

\begin{verroulevé}{Abandon de l'outil NVIDIA au profit d'un arbre de périphériques maîtrisé}
\textbf{Symptôme.} Impossible d'avoir \emph{en même temps} le pilote caméra et le PWM
matériel. Configurer l'un via \fichier{jetson-io.py} cassait l'autre.

\textbf{Cause racine.} \fichier{jetson-io.py} régénère et réapplique les \emph{overlays}
d'arbre de périphériques de façon globale : il écrase les configurations de multiplexage
existantes au lieu de les compléter.

\textbf{Correctif.} L'outil est \textbf{proscrit}. La configuration matérielle est gérée
par des \emph{overlays} explicites, versionnés, chargés depuis
\fichier{/boot/extlinux/extlinux.conf}. Les fichiers sont conservés dans
\fichier{jetson/} (voir \fichier{docs/annexes/jetson\_setup.md}).

\begin{avertissement}[Ne pas lancer \texttt{jetson-io.py}]
Sur une machine reconstruite selon ce dépôt, exécuter \fichier{jetson-io.py} et sauvegarder
\textbf{cassera la synchronisation stéréo}. L'\emph{overlay} PWM
(\fichier{jetson-io-hdr40-user-custom.dtbo}, broches 32 et 33) doit être préservé tel quel.
\end{avertissement}
\end{verroulevé}

% ---------------------------------------------------------------------
\subsection{Développer le protocole CAN avant d'avoir le bus}

\begin{verroulevé}{Bus virtuel \texttt{vcan0}}
Pour ne pas séquentialiser le projet derrière l'intégration matérielle, toute la couche
protocolaire a d'abord été développée et validée sur une interface CAN \textbf{virtuelle} :

\begin{lstlisting}[language=bash]
sudo modprobe vcan
sudo ip link add dev vcan0 type vcan && sudo ip link set up vcan0
candump vcan0
\end{lstlisting}

Les trames \texttt{TARGET\_VEC} (\texttt{0x020}, 7 octets) et \texttt{FIRE\_CMD}
(\texttt{0x010}) y ont été observées, correctement sérialisées, à la cadence attendue.
\texttt{vcan0} étant vu par SocketCAN exactement comme une interface réelle, le code
applicatif n'a eu \textbf{aucune ligne à changer} lors du passage sur \texttt{can0} physique.
C'était le but, et cela a marché : la sérialisation, les identifiants et les priorités étaient
justes du premier coup sur le cuivre.
\end{verroulevé}

% ---------------------------------------------------------------------
\subsection{Les transceivers CAN étaient des contrefaçons}
\label{sec:contrefacon}

\begin{verroulevé}{Clones 5~V vendus pour des SN65HVD230 3,3~V}
\textbf{Symptôme.} Comportement du bus \textbf{asymétrique}, ce qui n'a aucun sens sur un
bus différentiel. Relevé du noyau sur le Jetson :

\begin{lstlisting}[language=bash]
$ ip -details -statistics link show can0
  can state BUS-OFF (berr-counter tx 248 rx 0) restart-ms 100
  bitrate 500000 sample-point 0.870
  re-started  bus-errors  arbit-lost  error-warn  error-pass  bus-off
  20362       0           0           20363       20363       20363
  RX: bytes   packets  errors  dropped
      772684  111909   0       1
  TX: bytes   packets  errors  dropped
      121076  30458    0       26
\end{lstlisting}

\textbf{Lecture du relevé.} La réception est \emph{parfaite} : \textbf{111\,909 trames, zéro
erreur}. L'émission, elle, est morte : le compteur \texttt{TX} est figé sur la valeur
atteinte lors du dernier test en bouclage interne, le contrôleur part en \texttt{BUS-OFF} et
se relance 20\,362 fois. Le Jetson \emph{entend} parfaitement le STM32 ; il n'arrive pas à
lui \emph{répondre}.

\textbf{Cause racine.} Les modules \fichier{WCMCU-230}, vendus comme portant un
\textbf{SN65HVD230} de Texas Instruments (3,3~V), sont des \textbf{contrefaçons} : boîtiers
\textbf{poncés puis re-marqués au laser}, abritant un clone qui fonctionne en réalité en
\textbf{5~V}. D'où l'asymétrie : la sortie 5~V du module attaque sans peine l'entrée 3,3~V du
Jetson (réception impeccable), alors que la sortie 3,3~V du Jetson n'atteint jamais le seuil
logique haut de l'entrée 5~V du clone (émission jamais transmise sur le bus).

\textbf{Correctif.} Alimenter le module en \textbf{5~V} sur la broche sérigraphiée
« \texttt{3V3} », puis ramener sa sortie \texttt{CRX} vers l'entrée 3,3~V du Jetson par un
\textbf{pont diviseur résistif} 1~k$\Omega$ / 2~k$\Omega$. La sortie \texttt{CTX} du Jetson
(3,3~V) attaque directement le module sans adaptation.

\begin{avertissement}[Ne pas utiliser de convertisseur de niveau à MOSFET]
Les petites cartes bidirectionnelles à MOSFET et résistances de tirage (celles prévues pour
l'I\textsuperscript{2}C) sont \textbf{trop lentes pour du CAN à 500 kbit/s} : les fronts
deviennent des « ailerons de requin » que le contrôleur du Tegra classe en bruit et ignore.
Un simple pont diviseur, lui, n'introduit quasiment aucune capacité et garde le front franc.
\end{avertissement}

\textbf{Validation.} Le correctif a été qualifié sur un banc dédié à \textbf{deux ESP32}
identiques avant d'être reporté sur le matériel du projet — on ne rebranche pas un montage
douteux sur un Jetson à 300~\euro{}.
\end{verroulevé}

\noindent
Ce verrou est le plus coûteux du projet en temps, et le seul qu'aucune quantité de relecture
de code ne pouvait résoudre : \textbf{le défaut était dans le silicium, et le silicium
mentait sur son propre marquage.}

% =====================================================================
\newpage
\section{Verrous reportés}

% ---------------------------------------------------------------------
\subsection{Le bus CAN physique : la liaison a fonctionné, puis elle a été perdue}
\label{sec:can}

\begin{verroureporte}{CAN0 du Jetson — le routage des broches ne survit pas au démarrage à froid}
\textbf{Le bus a bel et bien fonctionné sur cuivre} : le Jetson a reçu \textbf{111\,909
trames du STM32, sans une seule erreur} (§\ref{sec:contrefacon}). Ce qui n'a pas été refermé
avant la fin du projet, c'est de rendre ce routage \textbf{persistant} — et de reconfirmer le
sens Jetson~$\rightarrow$~STM32 après la réparation des transceivers.
\end{verroureporte}

\paragraph{Ce qui est acquis, et qu'il ne faut pas refaire.} Le relevé du noyau du
21~mars~2026 est sans ambiguïté : \texttt{can0} est bien l'interface du contrôleur matériel
du Tegra (\texttt{parentdev c310000.mttcan}), à 500~kbit/s, et elle a encaissé
\textbf{111\,909 trames, 0 erreur de réception}, soit environ \textbf{une heure et demie} de
trafic \texttt{POS\_MOTION} continu à 20~Hz. Un tel compteur ne peut pas être produit par
l'écho local de SocketCAN : \textbf{ces trames sont physiquement arrivées par le cuivre.} Il
en découle, sans autre preuve à apporter, que le \emph{pinmux}, le câblage, la terminaison et
le \emph{bit timing} étaient \textbf{corrects}.

\paragraph{Ce qui restait ouvert.} Deux points, et deux seulement :
\begin{enumerate}
  \item \textbf{Le sens Jetson $\rightarrow$ STM32 n'a jamais été confirmé de bout en bout}
        \emph{après} la correction des transceivers contrefaits. Avant correction, il était
        en \texttt{BUS-OFF} — ce qui est \emph{expliqué} par la contrefaçon, mais n'a pas été
        re-testé une fois le pont diviseur en place.
  \item \textbf{L'\emph{overlay} de \emph{pinmux} a disparu de \fichier{/boot}.} Après le
        recâblage et un démarrage à froid, le Jetson est devenu sourd. Diagnostic final :
\end{enumerate}

\begin{lstlisting}[language=bash]
$ find /boot -name "*can*.dtbo"
$                                     # <- vide : le .dtbo n'est plus la

$ sudo bash -c "cat /sys/kernel/debug/pinctrl/*/pinmux-pins | grep -i paa"
pin 0 (CAN0_DOUT_PAA0): (MUX UNCLAIMED) (GPIO UNCLAIMED)
pin 1 (CAN0_DIN_PAA1):  (MUX UNCLAIMED) (GPIO UNCLAIMED)
\end{lstlisting}

\noindent
Le contrôleur \texttt{mttcan} se charge toujours et \texttt{can0} existe toujours — mais ses
broches ne sont plus \emph{réclamées} : le silicium CAN n'est plus relié à l'en-tête 40
broches. Le nœud émet dans le vide. \textbf{Ce n'est pas une régression logicielle : c'est le
binaire d'\emph{overlay} qui n'est plus là où le \emph{bootloader} va le chercher.}

\paragraph{Le piège de brochage.} Sur le Tegra 234 :
\begin{center}
\begin{tabular}{@{}lll@{}}
\toprule
\textbf{Broches SoC} & \textbf{Contrôleur} & \textbf{En-tête 40 broches} \\
\midrule
\broche{PAA0} / \broche{PAA1} & \textbf{CAN0} & broche 31 (TX) / broche 29 (RX) \\
\broche{PAA2} / \broche{PAA3} & CAN1 & — \\
\bottomrule
\end{tabular}
\end{center}

\noindent
Assigner la fonction \texttt{can0} aux broches \broche{PAA2}/\broche{PAA3} revient à demander
au silicium de router \emph{CAN0 sur les broches physiques de CAN1}. C'est l'erreur classique
sur cette carte, et elle ne produit aucun message d'erreur : simplement, plus rien ne sort.

\paragraph{L'\emph{overlay}, retrouvé et remis en place.} Le bon binaire a depuis été
récupéré : il est de nouveau dans \fichier{/boot}, référencé par la ligne \texttt{OVERLAYS}
de \fichier{/boot/extlinux/extlinux.conf} (modèle fourni :
\fichier{jetson/extlinux.conf.reference}), et sa copie de référence est versionnée dans
\fichier{jetson/dts/can0-pinmux.dtbo}, avec sa source \fichier{.dts}. Son en-tête interne
annonce « \texttt{CAN0 Hardware Override V5} » — cinquième itération. Il déclare les
n\oe uds corrects (\texttt{can0\_dout\_paa0}, \texttt{can0\_din\_paa1}, fonction
\texttt{can0}) et neutralise \texttt{paa2}/\texttt{paa3}. \textbf{C'est cette version qui a
produit les 111\,909 trames.}

\begin{avertissement}[Une hypothèse répandue — et fausse]
La dernière piste explorée avant l'arrêt du projet attribuait la panne à un \emph{overlay}
\fichier{jetson-io-hdr40-user-custom.dtbo} « empoisonné », qui aurait contenu une mauvaise
affectation CAN sur \broche{PAA2}/\broche{PAA3}.

\textbf{Cette hypothèse est démentie par le fichier lui-même.} Son inspection (juillet 2026)
montre qu'il ne configure \emph{que} deux broches :
\texttt{hdr40-pin32}~$\rightarrow$~\texttt{soc\_gpio19\_pg6} et
\texttt{hdr40-pin33}~$\rightarrow$~\texttt{soc\_gpio21\_ph0} — les broches du PWM de
synchronisation. \textbf{Il ne contient aucune configuration CAN.}

Ne pas perdre de temps à « réparer » ce fichier : il n'est pas en cause, et le modifier
casserait la synchronisation stéréo. La cause est ailleurs.
\end{avertissement}

\paragraph{Procédure de reprise.} Il ne s'agit pas d'une recherche, mais d'une remise en
état. Dans l'ordre :
\begin{enumerate}
  \item \textbf{Vérifier l'\emph{overlay}} : \fichier{can0-pinmux.dtbo} doit être dans
        \fichier{/boot} et sur la ligne \texttt{OVERLAYS} de \fichier{extlinux.conf} — il y
        est en l'état. S'il a disparu (mise à jour JetPack), le recopier depuis
        \fichier{jetson/dts/} et redémarrer.
  \item \textbf{Vérifier que les broches sont réclamées} — c'est le contrôle qui tranche :
\begin{lstlisting}[language=bash]
sudo bash -c "cat /sys/kernel/debug/pinctrl/*/pinmux-pins | grep -i paa"
# ATTENDU : pin 0 (CAN0_DOUT_PAA0): c310000.mttcan  <- reclamee
# ECHEC   : pin 0 (CAN0_DOUT_PAA0): (MUX UNCLAIMED) <- overlay non applique
\end{lstlisting}
  \item \textbf{Remonter le montage transceiver} avec le correctif 5~V + pont diviseur
        (§\ref{sec:contrefacon}) — \emph{et non} le câblage 3,3~V « théorique ».
  \item \textbf{Confirmer les deux sens} : \texttt{candump can0} doit montrer les trames
        \texttt{030} du STM32 \emph{et} le compteur \texttt{TX} du Jetson doit progresser
        sans partir en \texttt{BUS-OFF}.
\end{enumerate}

\begin{avertissement}[Le piège qui a coûté le bus : une mise à jour efface \fichier{/boot}]
Une mise à jour de JetPack, ou toute opération qui régénère \fichier{/boot}, peut
\textbf{supprimer silencieusement} le \fichier{.dtbo} sans toucher à la ligne
\texttt{OVERLAYS} qui le référence. Le \emph{bootloader} ne trouve pas le fichier,
\textbf{n'émet aucune erreur}, et démarre sans l'\emph{overlay}. Le système est alors
\emph{exactement} identique à un système sain — sauf que le CAN est muet.

Après \textbf{toute} mise à jour du Jetson, vérifier :
\texttt{find /boot -name "*can*.dtbo"}. Si la commande ne renvoie rien, le bus est mort et
c'est la seule chose à réparer.
\end{avertissement}

\paragraph{Repli, si le \emph{pinmux} résiste.} Un contrôleur CAN \textbf{externe sur SPI}
(MCP2515 ou équivalent) donne un bus fonctionnel sans dépendre du \emph{pinmux} du Tegra ni
de son arbre de périphériques. On perd le CAN natif ; on gagne l'immunité aux mises à jour de
JetPack. \textbf{Sous contrainte de temps, c'est l'option raisonnable.}

\paragraph{Ce que ce verrou n'est pas.} Il n'est ni logiciel, ni protocolaire, ni un défaut
de conception du bus. Le protocole a tourné sur le cuivre. \textbf{Seule la persistance du
routage des broches est en cause.}

% ---------------------------------------------------------------------
\newpage
\subsection{Reconnaissance biologique : VespAI est en couleur, nos capteurs non}

\begin{verroureporte}{Incompatibilité VespAI / capteur monochrome}
\textbf{Le système ne sait pas reconnaître un frelon.} Il suit un marqueur ArUco.
\end{verroureporte}

\begin{figure}[htbp]
  \centering
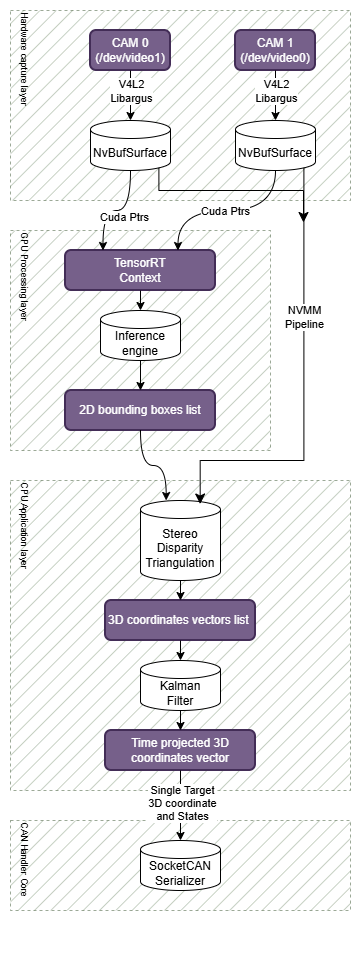
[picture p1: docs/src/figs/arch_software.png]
  
  \caption{\textbf{Le pipeline de vision tel qu'il était prévu — et tel qu'il n'a pas été
  livré.} Le bloc \emph{TensorRT Context} / \emph{Inference engine} devait porter la
  détection biologique sur GPU. C'est précisément ce bloc qui est tombé : il est remplacé,
  dans le système livré, par une détection de \textbf{marqueur ArUco} sur CPU (OpenCV). Tout
  le reste de la chaîne — triangulation stéréo, filtre de Kalman, sérialisation SocketCAN —
  est en revanche opérationnel et conforme à ce schéma. Le n\oe ud de vision ne dépend donc
  aujourd'hui \textbf{ni de CUDA, ni de TensorRT, ni de VPI}.}
  \label{fig:arch-software}
\end{figure}

\paragraph{L'enchaînement des contraintes.} Ce verrou n'est pas une erreur : c'est une
cascade logique dont chaque maillon est justifié, et dont le résultat est une impasse.

\begin{enumerate}
  \item Le flou de mouvement détruit la détection $\rightarrow$ il faut un
        \textbf{obturateur global}.
  \item Aucun capteur \textbf{trichrome} à obturateur global n'existe à un prix accessible
        $\rightarrow$ le capteur sera \textbf{monochrome} (OV9281).
  \item Le modèle VespAI~\cite{osheawheller2024vespai} est entraîné sur des images
        \textbf{RGB} $\rightarrow$ \textbf{incompatible}.
\end{enumerate}

\paragraph{Ce qui a été tenté.} Une « chirurgie réseau » sur les poids pré-entraînés, sans
réentraînement. L'idée est mathématiquement exacte : si l'on duplique le canal gris sur les
trois canaux RGB, la première convolution calcule
\[
  \text{sortie} = I_R W_R + I_G W_G + I_B W_B
  = I_{\text{gris}}\,(W_R + W_G + W_B),
\]
donc \textbf{sommer les poids de la première couche sur la dimension canal} produit un
modèle à 1 canal \emph{strictement équivalent}, sans perte, sans jeu de données, sans
entraînement.

\begin{lstlisting}[language=Python]
new_weights = torch.sum(old_weights, dim=1, keepdim=True)  # (out,3,k,k) -> (out,1,k,k)
first_conv_layer.weight      = nn.Parameter(new_weights)
first_conv_layer.in_channels = 1
\end{lstlisting}

\paragraph{Pourquoi cela a échoué quand même.} La transformation est exacte, et le modèle
obtenu tourne vite (compilé en TensorRT FP16, entrée native
$1{,}280 \times 800$ — les deux dimensions étant multiples de 32, aucun redimensionnement
n'est requis, donc pas de recours au VIC). \textbf{Mais l'équivalence mathématique ne crée
pas d'information.} Le modèle reste entraîné sur des statistiques de couleur : il détecte des
frelons \emph{imprimés sur papier blanc}, et échoue en conditions réelles, avec des faux
positifs massifs. Surtout, la distinction \emph{V.~velutina} / \emph{V.~crabro} — l'exigence
éthique centrale du projet — repose largement sur la \textbf{coloration}
\cite{sipos2025morphologie} : elle est \textbf{structurellement impossible} en monochrome à
partir d'un modèle couleur.

\paragraph{Décision.} À trois semaines de la soutenance, le réentraînement complet
(estimé 1,5 à 2,5 semaines, sans garantie de résultat, le jeu de données n'étant pas public)
a été jugé trop risqué. \textbf{Repli assumé sur un marqueur ArUco}
\cite{garridojurado2014aruco} : haut contraste, natif en niveaux de gris, aucun
entraînement, pose 3D exacte. Le marqueur \textbf{tient lieu de cible} et permet de valider
toute la chaîne aval (triangulation, prédiction, asservissement) — qui est, elle,
indépendante de la nature de la cible.

\begin{note}[Pour la reprise]
La voie n'est pas la « chirurgie réseau ». C'est la \textbf{constitution d'un jeu de données
monochrome} (images issues de l'OV9281 lui-même, en conditions réelles) et le
réentraînement d'un détecteur dessus. Tant que la discrimination inter-espèces ne sera pas
rétablie, \textbf{le système ne doit pas tirer} : il ne sait pas distinguer une espèce
invasive d'une espèce protégée.
\end{note}

% ---------------------------------------------------------------------
\subsection{Le n\oe ud de coordination, le watchdog, et le tir}

\begin{verroureporte}{Watchdog non implémenté — laser jamais mis sous tension}
Le \fichier{coordination\_node} (ESP32) \textbf{n'existe pas}. Il est spécifié — ses trames
CAN sont définies (\texttt{FIRE\_CMD}, \texttt{POS\_COORD}, \texttt{HB\_COORD}) — mais
aucune ligne de code ne l'implémente.
\end{verroureporte}

Or ce n\oe ud porte trois fonctions, dont une est une condition de sécurité :

\begin{center}
\begin{tabularx}{\textwidth}{@{}lX@{}}
\toprule
\textbf{Fonction} & \textbf{État} \\
\midrule
Collimation dynamique & Loi de commande établie, mécanisme spécifié, jamais assemblé \\
Séquence de tir & Non implémentée \\
\textbf{Watchdog} & \textbf{Non implémenté} — \emph{condition sine qua non du tir} \\
\bottomrule
\end{tabularx}
\end{center}

\paragraph{Conséquence, et elle est délibérée.} Le watchdog est le mécanisme qui surveille
les \emph{heartbeats} de tous les n\oe uds et coupe l'alimentation générale en cas de
défaut ou de silence. Sans lui, \textbf{rien ne garantit l'extinction du laser si un n\oe ud
se fige}.

\begin{avertissement}[La diode laser n'a jamais été alimentée]
Ce n'est pas un retard : c'est un \textbf{refus}. Mettre sous tension une diode de
\textbf{Classe 4} (voir \fichier{docs/annexes/securite\_laser.md}) sans \emph{interlock}
fonctionnel aurait été une faute. Aucun tir n'a été effectué, et \textbf{aucun ne doit
l'être} tant que le watchdog n'est pas opérationnel et testé.
\end{avertissement}

\paragraph{Note de conception.} Le watchdog est prévu \emph{dans le n\oe ud de tir} —
c'est-à-dire au plus près de l'organe dangereux, sur un c\oe ur CPU dédié. C'est le bon
choix : un superviseur qui dépendrait du réseau pour couper le courant serait vulnérable à
la panne même qu'il doit traiter. La coupure est \textbf{matérielle} (alimentation
générale), l'inhibition logicielle du tir n'intervenant que pendant le temps de décharge des
condensateurs.

% ---------------------------------------------------------------------
\subsection{La profondeur de champ létale : un résultat inattendu}

\begin{verroureporte}{Collimation dynamique — jamais assemblée ni étalonnée}
\end{verroureporte}

Le mécanisme de collimation dynamique vise à \textbf{dégrader volontairement} le faisceau
partout ailleurs qu'au point d'impact, afin de réduire la dangerosité intrinsèque du
dispositif. Deux lentilles : \textbf{L1} (fournie avec le module, rapprochée de la source
pour la faire \emph{diverger}) et \textbf{L2} (longue focale, mobile, qui refocalise à une
distance commandée).

La loi de commande a été établie analytiquement par les relations de conjugaison de
Descartes, en éliminant la focale inconnue $f_1$ au profit de grandeurs mesurables
(demi-divergence $\theta$, diamètre $D_{L2}$ du faisceau sur la lentille mobile) :
\[
  x_{\text{cible}} \;=\; x_{L2} \;+\;
  \frac{f_2 \cdot \dfrac{D_{L2}}{2\tan\theta}}
       {\dfrac{D_{L2}}{2\tan\theta} - f_2}
\]
Cette relation, quadratique, est approximée par un polynôme à $10^{-4}$~mm près — plus
rapide à évaluer sur microcontrôleur.

\paragraph{Le résultat qu'il faut retenir.} Le tracé de densité de puissance
(\fichier{simulation/optique/Laser\_Optics\_v1.m}) donne deux enseignements
\textbf{opposés}, et c'est le second qui compte :

\begin{itemize}
  \item \textcolor{vespagreen}{\textbf{Bonne nouvelle.}} Le seuil d'embrasement de matières
        sèches n'est franchi que sur $\approx 50$~mm de part et d'autre de la cible. Un tir
        manqué venant frapper le sol présente donc un risque d'incendie
        \textbf{limité}. L'objectif du mécanisme est atteint.
  \item \textcolor{vespared}{\textbf{Mauvaise nouvelle, et elle domine.}} Le seuil de
        dangerosité \textbf{oculaire} reste dépassé sur près de \textbf{200~mètres}. La
        collimation dynamique \textbf{ne rend pas le dispositif sûr} : elle réduit le risque
        d'incendie, pas le risque oculaire.
\end{itemize}

\begin{avertissement}
Il serait dangereux de conclure de ce mécanisme que le système est « moins dangereux ».
Il ne l'est pas pour l'\oe il. La collimation dynamique est une mesure de mitigation
\textbf{partielle}, en aucun cas un substitut aux protections (lunettes, \emph{interlock},
confinement).
\end{avertissement}

% ---------------------------------------------------------------------
\subsection{Verrous mineurs et dette technique}

\begin{center}
\begin{tabularx}{\textwidth}{@{}p{4.2cm}Xl@{}}
\toprule
\textbf{Sujet} & \textbf{Description} & \textbf{État} \\
\midrule
Appels \texttt{std::system} &
Le pilotage du PWM passe par des appels shell (\texttt{echo > /sys/class/pwm/...}).
Coûteux et fragile. À remplacer par des écritures \texttt{sysfs} directes en C++. &
Ouvert \\
\addlinespace
Chemins absolus &
Les \texttt{\#define} de scripts PWM sont des chemins absolus : déplacer le dépôt casse la
compilation. À rendre relatifs ou configurables. &
Ouvert \\
\addlinespace
Échelle d'exposition &
L'OV9281 n'utilise pas le même calcul de temps-ligne en mode maître et en mode
déclenchement externe. L'outil \fichier{app\_EG.py} calibre donc dans un régime différent
de celui du \emph{pipeline} C++ : les valeurs ne correspondent pas 1:1. &
Ouvert \\
\addlinespace
Timing des contrôles V4L2 &
Attendre que le flux tourne avant de pousser les réglages. &
\textcolor{vespagreen}{\textbf{Clos}} \\
\addlinespace
Suivi multi-cibles &
Un seul filtre de Kalman. Une nuée de frelons n'est pas gérée : ni association de données,
ni priorisation. &
Ouvert \\
\bottomrule
\end{tabularx}
\end{center}

% =====================================================================
\newpage
\section{Ce que l'assistance par IA a coûté, et ce qu'elle a rapporté}
\label{sec:ia}

Cette section est inhabituelle dans un document technique. Elle est ici parce que le projet
a été, de bout en bout, co-développé avec des modèles de langage, et que \textbf{le bilan
n'est pas uniforme}. Un repreneur qui adopterait la même méthode doit savoir où elle porte
et où elle nuit.

\paragraph{Ce qui a très bien fonctionné.} La production de code. Le volume de logiciel écrit
— chaîne V4L2 zéro-copie, sérialisation CAN, FOC, triangulation, filtre de Kalman, outils
web de calibration — est hors de portée de trois étudiants sur la durée impartie sans cette
assistance. Le rapport de soutenance le dit, et c'est exact.

\paragraph{Ce qui a coûté cher.} \textbf{Le diagnostic matériel.} Les modèles produisent des
hypothèses plausibles, argumentées, confiantes — et fausses. Elles sont d'autant plus
coûteuses qu'elles sont \emph{crédibles} : elles envoient chercher au mauvais endroit,
parfois pendant des jours.

\begin{center}
\begin{tabularx}{\textwidth}{@{}p{5.2cm}X@{}}
\toprule
\textbf{Affirmation de l'IA} & \textbf{Réalité établie par la mesure} \\
\midrule
« Deux OV9281 exigent un multiplexeur I\textsuperscript{2}C matériel » &
Faux. Chaque port CSI a son propre bus. Un \emph{overlay} adapté suffit. \\
\addlinespace
« \fichier{jetson-io.py} : sélectionnez \texttt{can0}, cela routera les broches » &
Faux, et destructeur : l'outil écrase la configuration caméra/PWM. \\
\addlinespace
« L'\emph{overlay} \fichier{jetson-io-hdr40-\allowbreak user-custom.dtbo} est empoisonné : il assigne
CAN0 à \broche{PAA2}/\broche{PAA3} » &
\textbf{Faux.} Inspection du binaire : il ne contient \emph{que} les deux broches PWM
(32 et 33). Aucune configuration CAN. \textbf{Le projet s'est arrêté sur cette fausse
piste.} \\
\addlinespace
« Le bus CAN est muet : l'autre n\oe ud est en mode \emph{listen-only} / votre
convertisseur de niveau est trop lent / votre code d'init est faux » &
\textbf{Toutes fausses.} Le défaut était dans le \emph{silicium} : des transceivers
contrefaits (§\ref{sec:contrefacon}). Aucune hypothèse logicielle ne pouvait y mener. La
cause a été trouvée en \textbf{regardant physiquement la puce} — poncée, re-marquée. \\
\addlinespace
« La chirurgie réseau donnera un détecteur équivalent » &
Mathématiquement exact, \textbf{opérationnellement faux} : l'équivalence formelle ne
compense pas l'absence d'information couleur. \\
\bottomrule
\end{tabularx}
\end{center}

\paragraph{La règle qui s'en dégage.} Sur ce projet, \textbf{toutes} les avancées matérielles
décisives sont venues d'une \emph{mesure} qui contredisait une hypothèse — pas d'un
raisonnement. Le conflit \broche{PA2}/série a été trouvé en débranchant. La contrefaçon des
transceivers a été trouvée \textbf{à l'\oe il, sur la puce} — après que le modèle eut proposé,
avec assurance, quatre causes logicielles successives toutes fausses. La fausse piste finale
sur l'\emph{overlay} aurait été écartée en \emph{ouvrant le fichier incriminé} — ce qui prend
deux minutes, et n'a pas été fait.

\medskip
\noindent
Le contre-exemple est instructif : c'est la seule fois où le relevé brut a été lu \emph{pour
ce qu'il disait} — une réception parfaite face à une émission morte — que la cause est
devenue évidente. \textbf{Un bus différentiel ne peut pas être asymétrique. C'est l'anomalie
qui portait la réponse}, et elle était visible dès le premier
\texttt{ip -s link show can0}.

\begin{note}[Recommandation au repreneur]
Utilisez ces outils pour écrire du code : le gain est réel et considérable. Mais devant un
symptôme matériel, \textbf{n'acceptez aucune cause racine qui n'ait été confirmée par une
mesure}. Le coût d'une vérification est presque toujours inférieur au coût d'une fausse
piste bien argumentée.
\end{note}

% =====================================================================
\newpage
\section{Synthèse : par où reprendre}

\begin{center}
\begin{tabularx}{\textwidth}{@{}clX@{}}
\toprule
\textbf{\#} & \textbf{Chantier} & \textbf{Pourquoi dans cet ordre} \\
\midrule
1 & \textbf{Remettre le CAN physique en service} &
Le bus a déjà fonctionné (111\,909 trames, 0 erreur) et l'\emph{overlay}
\fichier{can0-pinmux.dtbo} est en place dans \fichier{/boot}. Il ne reste qu'à remonter les
transceivers avec le correctif 5~V et à reconfirmer le sens émission.
\textbf{C'est une remise en état, pas une recherche.} \\
\addlinespace
2 & \textbf{Implémenter le watchdog} &
Condition \emph{sine qua non} de toute mise sous tension du laser de Classe 4.
Aucun essai de tir avant cela. \\
\addlinespace
3 & \textbf{Jeu de données monochrome + réentraînement} &
Rend au système sa fonction biologique et la discrimination inter-espèces. Sans cela, le
système ne doit pas tirer. \\
\addlinespace
4 & \textbf{Assembler et étalonner la collimation} &
Loi de commande établie ; mécanisme jamais monté. Attention : ne réduit
\emph{pas} le risque oculaire. \\
\addlinespace
5 & \textbf{Gestion multi-cibles} &
Un filtre de Kalman par cible + association de données. \\
\bottomrule
\end{tabularx}
\end{center}
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

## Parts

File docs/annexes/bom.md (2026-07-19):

# Annexe — Nomenclature (BOM)

Nomenclature du prototype **mk.2**, **telle que réellement montée**.
Total en fin de page. Les prix de la colonne `Prix TTC` sont des **prix de ligne**
(quantité comprise), et non des prix unitaires.

---

## Calcul et électronique

| Élément | Fournisseur | Qté | Prix TTC |
|---|---|---:|---:|
| Jetson Orin Nano Super Developer Kit | RS Online | 1 | 311,18 € |
| NUCLEO-G431RB — *MCU du `motion_node`* | Farnell France | 1 | 22,08 € |
| X-NUCLEO-IHM16M1 (STSPIN830) — *étages de puissance* | Farnell France | 2 | 36,22 € |
| ESP32-C3 SuperMini — *nœud de coordination, jamais implémenté* | AliExpress | 1 | 4,29 € |
| Alimentation AC-DC 24 V / 150 W | AliExpress | 1 | 5,29 € |
| Transceivers CAN WCMCU-230 (lot de 10) — ⚠️ **contrefaits, voir ci-dessous** | AliExpress | 1 | 5,19 € |
| TMC2209 (lot de 4) — *pilotage collimation* | AliExpress | 1 | 9,09 € |

> **Les deux shields IHM16M1 sont câblés côte à côte, et non empilés sur la Nucleo.**
> Ce n'est pas un détail de confort : empilés, la broche `A5` (qu'il faut tirer à 3,3 V pour
> sortir le STSPIN830 de veille) est reliée à `PC0`, qui sert de retour de courant `SENSEU`
> au moteur 2. L'empilement saturerait cette entrée et casserait la boucle de courant.

## Vision

| Élément | Fournisseur | Qté | Prix TTC |
|---|---|---:|---:|
| Module Arducam OV9281 1 MP monochrome *global shutter* | Arducam | 2 | 142,59 € |
| Objectif M12 5 MP 4,6 mm sans distorsion | AliExpress | 2 | 9,29 € |

## Mécanique et actionneurs

| Élément | Fournisseur | Qté | Prix TTC |
|---|---|---:|---:|
| iFlight iPower GM5208-12 + encodeur AS5048A (paire) | AliExpress | 1 | 134,99 € |
| Actionneur linéaire course 35 mm | AliExpress | 1 | 20,42 € |
| Capteur photoélectrique en U — *prise d'origine* | AliExpress | 1 | 2,54 € |

## Optique de tir

| Élément | Fournisseur | Qté | Prix TTC |
|---|---|---:|---:|
| **Diode laser bleue 5,5 W** — ⚠️ **Classe 4** | AliExpress | 1 | 83,69 € |
| Lentille asphérique K9 D63 F100 — *lentille L2, focale 100 mm* | AliExpress | 1 | 23,59 € |

## Sécurité — non optionnel

| Élément | Fournisseur | Qté | Prix TTC |
|---|---|---:|---:|
| **Lunettes de protection OD7+ CE 190–550 nm** | AliExpress | 1 | 30,29 € |

## Total

| | Prix TTC |
|---|---:|
| Calcul et électronique | 393,34 € |
| Vision | 151,88 € |
| Mécanique et actionneurs | 157,95 € |
| Optique de tir | 107,28 € |
| Sécurité | 30,29 € |
| **TOTAL** | **840,74 €** |

---

## ⚠️ Les transceivers CAN du lot sont des contrefaçons

Les modules **WCMCU-230** de ce lot sont vendus comme portant un **SN65HVD230** de Texas
Instruments (3,3 V). Ce sont des **clones 5 V** : les boîtiers ont été **poncés puis
re-marqués au laser**.

Câblés en 3,3 V comme le voudrait la théorie, ils donnent un bus **asymétrique** —
réception parfaite, émission morte — ce qui est impossible sur un bus différentiel et
constitue la signature du défaut.

| | Vrai SN65HVD230 | Le clone livré |
|---|---|---|
| Alimentation | 3,3 V | **5 V** (sur la broche sérigraphiée « 3V3 ») |
| Sortie `CRX` | 3,3 V, directe | **5 V** → **pont diviseur 1 kΩ / 2 kΩ** vers le Jetson |
| Entrée `CTX` | 3,3 V | Le 3,3 V du Jetson suffit à l'attaquer, sans adaptation |

> **Ne pas utiliser de convertisseur de niveau à MOSFET.** Ces petites cartes
> bidirectionnelles (prévues pour l'I²C) sont trop lentes à 500 kbit/s : les fronts
> s'arrondissent et le contrôleur CAN du Tegra les rejette comme du bruit. Un pont diviseur
> résistif n'a quasiment aucune capacité et garde le front franc.

**Vérifier lequel des deux vous avez avant de câbler.** Voir *Difficultés techniques*.

---

## Le laser : 5 W au calcul, 5,5 W à l'achat

| Source | Spécification |
|---|---|
| **Nomenclature** (matériel acheté) | **5,5 W**, bleu |
| **Rapport de soutenance** (dimensionnement théorique) | 5 W à 460 nm |

Les deux sont cohérentes en ordre de grandeur : le calcul d'irradiance (≈ 2 200 W/cm² sur
un spot de 0,53 mm) a été mené pour 5 W, la diode physiquement présente fait 5,5 W.
**Classe 4 dans les deux cas.** Voir [`securite_laser.md`](securite_laser.md).

---

## Caractéristiques du moteur GM5208-12

Source : [`hardware/mechanical/motor/GM5208-12.json`](../../hardware/mechanical/motor/GM5208-12.json)

| Paramètre | Valeur |
|---|---|
| Type | PMSM *pancake* (gimbal), 14 aimants |
| Paires de pôles | **7** |
| Résistance statorique `Rs` | 7,48 Ω |
| Inductance `Ls` | 4,49 mH |
| Tension nominale | 23,6 V |
| Courant nominal | 1,5 A |
| Vitesse max. | 504 |
| Constante de FEM | 32,96 |
| Encodeur | **AS5048A**, magnétique absolu **14 bits** |
| Résolution angulaire théorique | 360 / 2¹⁴ ≈ **0,022°** |

---

## Nomenclature du prototype mk.1 (pour mémoire)

Le premier prototype (Cosson & Grimal, 2024/2025) utilisait un matériel radicalement
différent, dont les limites ont motivé le mk.2. Son rapport, remis avec la mention
« Confidentiel », est cité pour référence dans la bibliographie mais **n'est pas rediffusé
dans ce dépôt** :

- Arduino Uno (ATmega328P — **pas de FPU**, d'où le *jitter* sur les rampes d'accélération)
- Moteurs pas-à-pas + shield **DRV8825** (microstepping 1/32) — **décrochage**,
  dérive cumulative, aucun retour de position
- Détection **YOLOv8** déportée sur PC, liaison Python ↔ Arduino par port série
- Diode laser rouge 650 nm, **10 mW** — sans capacité de neutralisation
- **Monoculaire** : aucune mesure de distance, donc aucune collimation possible

Le code de caractérisation de ce banc est conservé dans
[`software/legacy_mk1_bench/`](../../software/legacy_mk1_bench/) : ce sont les annexes A à D
du rapport de soutenance.

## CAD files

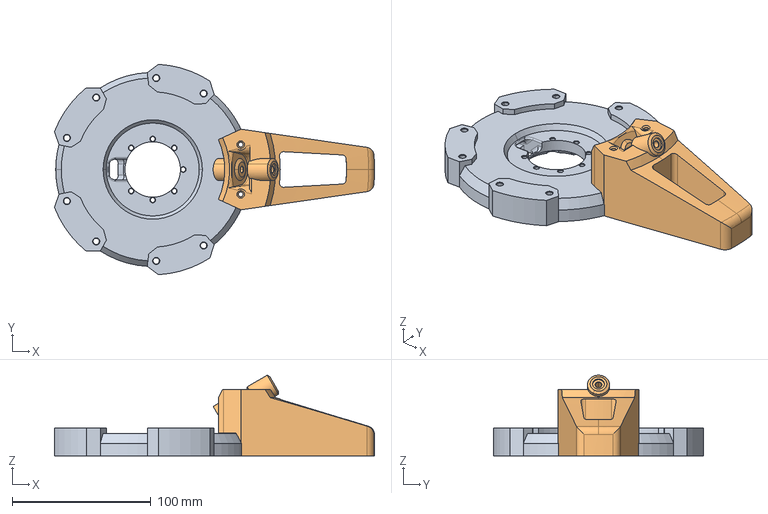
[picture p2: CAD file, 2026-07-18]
hardware/mechanical/cad/VESPA_ASY_Base_A.1_WIP.step
230.9 x 151.8 x 58.2 mm
ADEL_VESPA_Base_Hub
ADEL_VESPA_Base_Leg

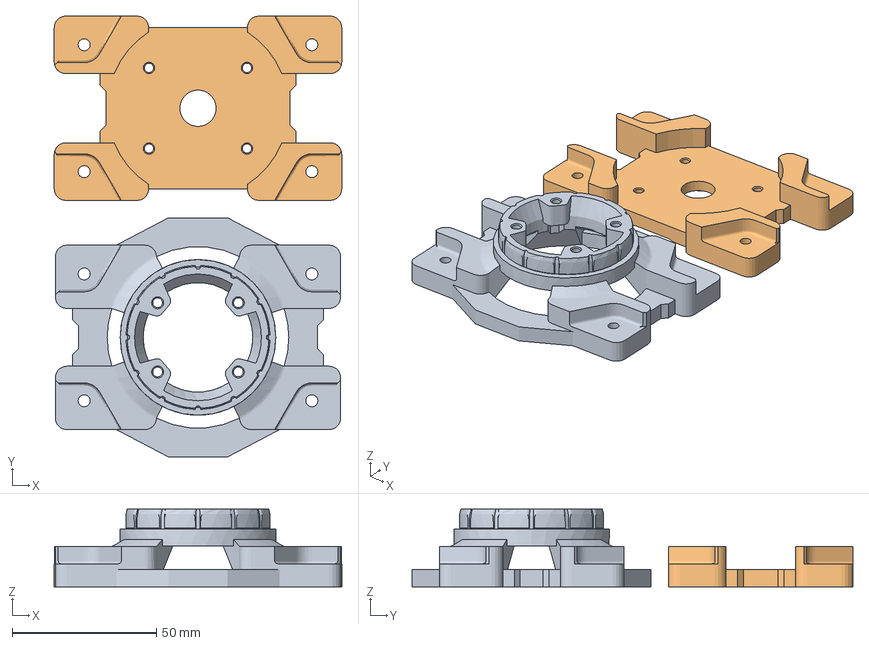
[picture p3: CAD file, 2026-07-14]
hardware/mechanical/print/plates/PLATE_BearingMount_MotorMount.3mf
99.8 x 153.0 x 27.0 mm
ADEL_VESPA_Turret_BearingMount A.1
ADEL_VESPA_Turret_MotorMount A.1

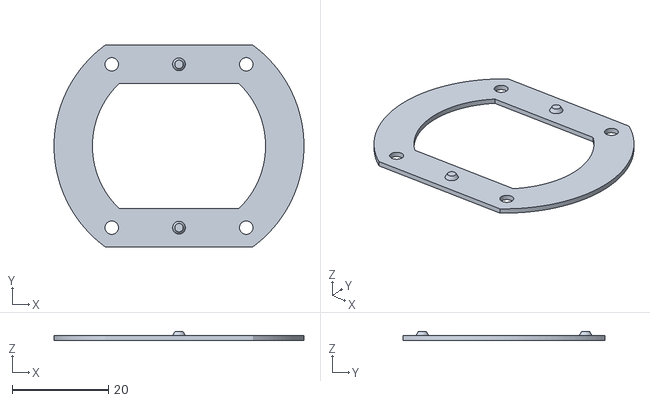
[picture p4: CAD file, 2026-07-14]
hardware/mechanical/print/VESPA_Frame_JointB2_A.1.stl
52.0 x 42.0 x 1.80

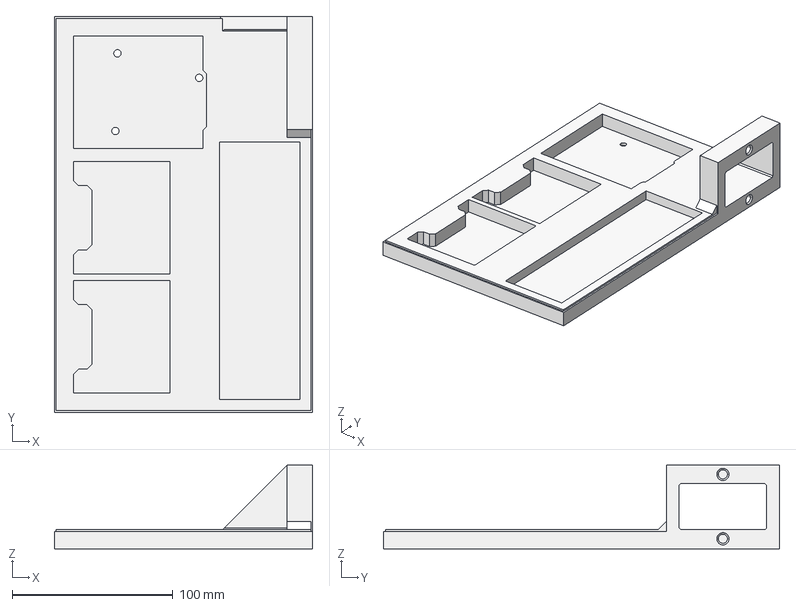
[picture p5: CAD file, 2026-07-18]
hardware/mechanical/cad/VESPA_Bench_BoardPlate_A.1.step
160.5 x 246.0 x 52.0 mm

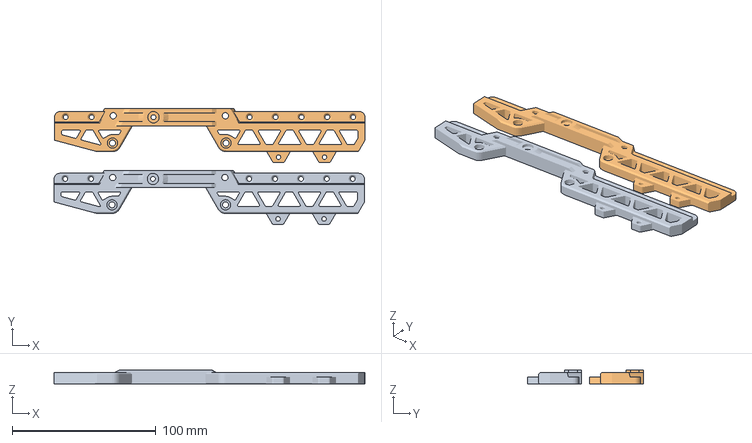
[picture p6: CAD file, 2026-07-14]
hardware/mechanical/print/plates/PLATE_RailType2_x2.3mf
216.3 x 80.6 x 10.0 mm

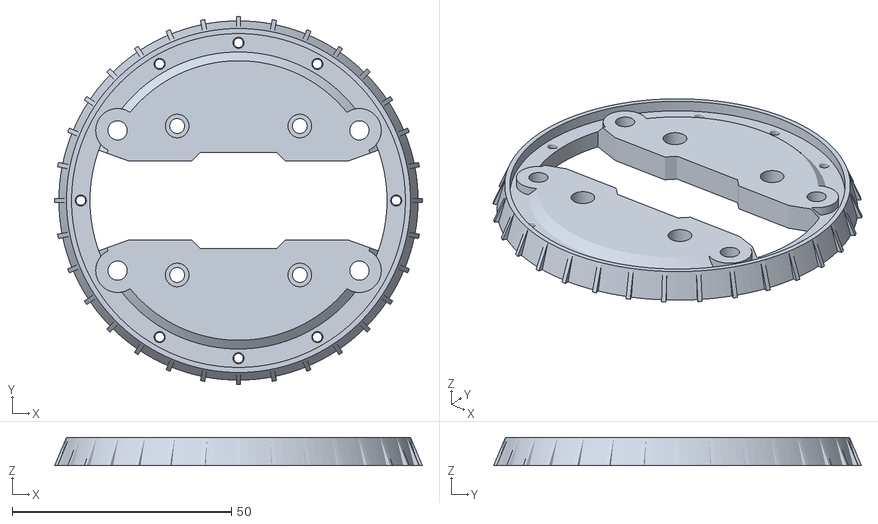
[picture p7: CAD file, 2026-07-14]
hardware/mechanical/print/VESPA_Frame_LinkB1_A.1.stl
84.0 x 84.0 x 6.50

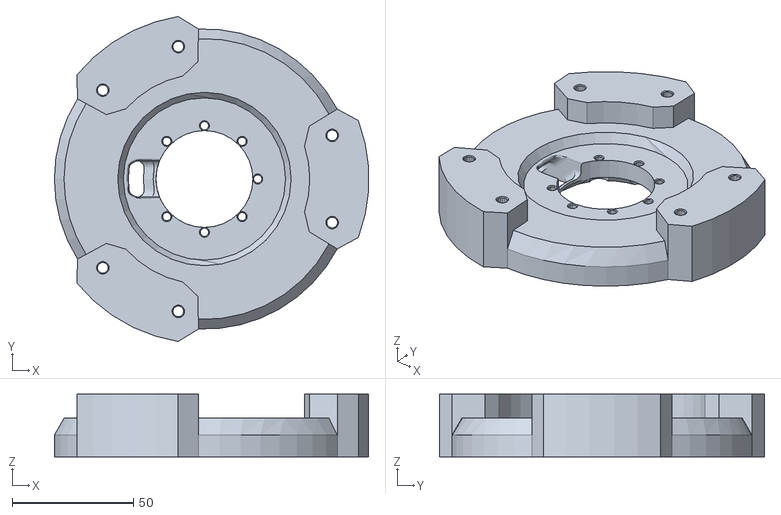
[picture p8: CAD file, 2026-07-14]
hardware/mechanical/print/VESPA_Base_Hub_A.1.stl
129.8 x 134.2 x 26.0

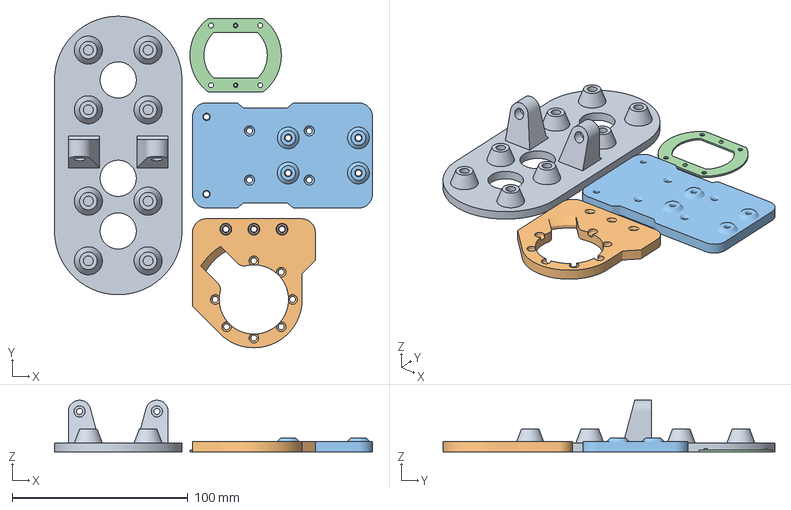
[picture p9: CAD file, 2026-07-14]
hardware/mechanical/print/plates/PLATE_Structural_x4.3mf
181.1 x 188.8 x 29.4 mm
ADEL_VESPA_Turret_ShieldLite A.1.stl
ADEL_VESPA_Link_BracketLeft A.1.stl
ADEL_VESPA_Turret_MotorPlate A.1.stl
ADEL_VESPA_Frame_JointB2 A.1.stl

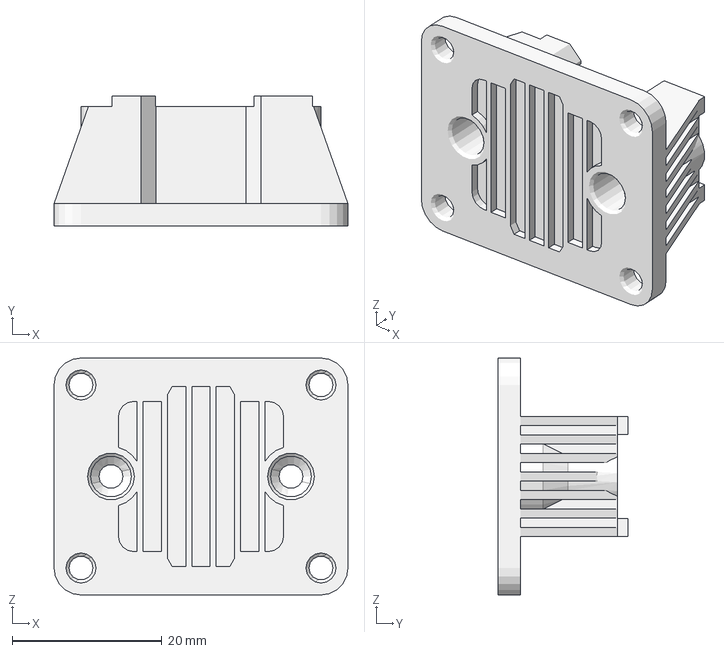
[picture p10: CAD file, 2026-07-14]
hardware/mechanical/print/VESPA_Turret_LABracket_A.1.3mf
39.2 x 17.4 x 31.6 mm

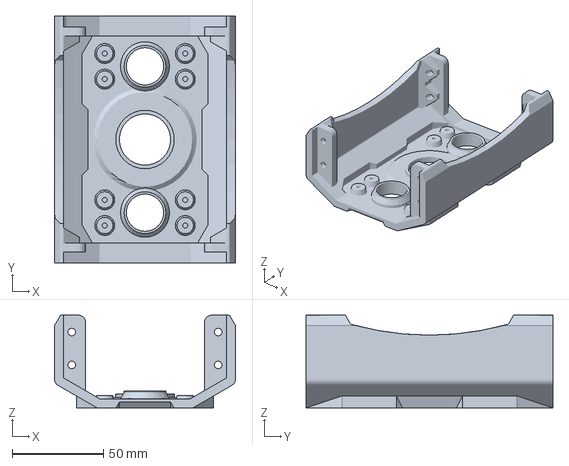
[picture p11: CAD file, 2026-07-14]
hardware/mechanical/print/plates/PLATE_FrontShield_flat.3mf
99.0 x 135.0 x 50.8 mm

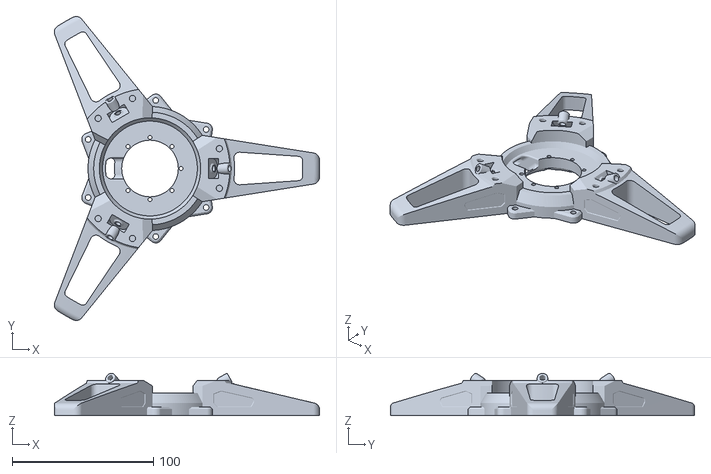
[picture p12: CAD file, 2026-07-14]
hardware/mechanical/print/VESPA_Frame_BaseA_A.2.stl
187.7 x 215.0 x 29.9

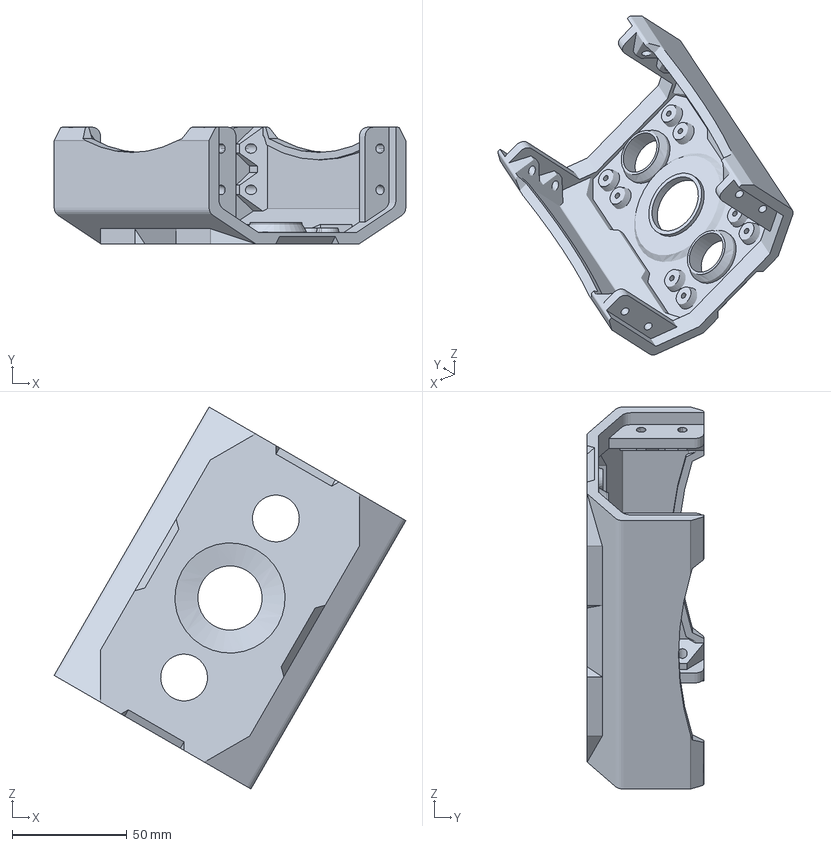
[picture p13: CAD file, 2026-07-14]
hardware/mechanical/print/plates/PLATE_FrontShield_tilted.3mf
153.2 x 50.8 x 166.4 mm

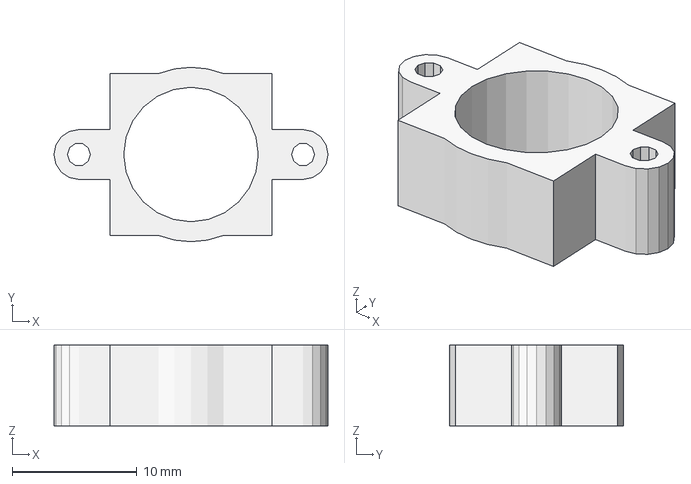
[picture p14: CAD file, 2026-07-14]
hardware/mechanical/print/VESPA_Optics_LensHolderSpacer_A.1.3mf
22.0 x 14.0 x 6.50 mm

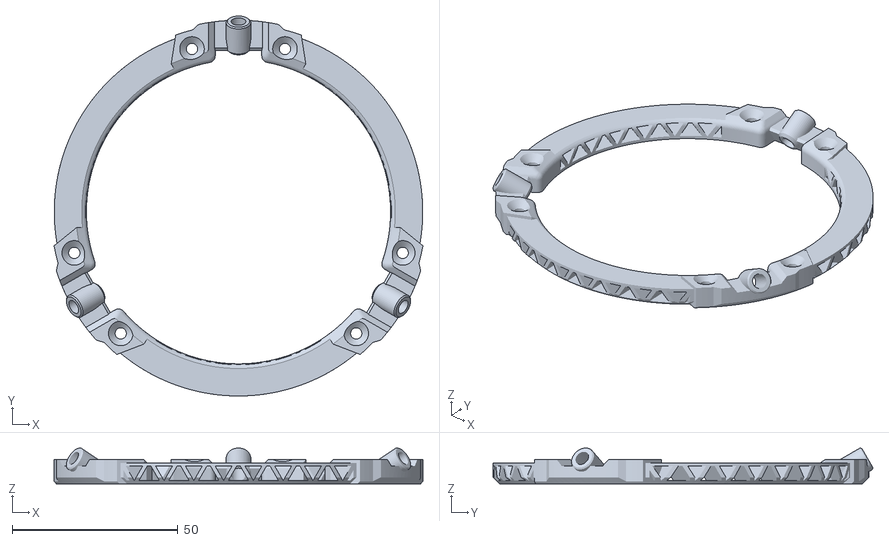
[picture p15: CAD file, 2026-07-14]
hardware/mechanical/print/VESPA_Frame_BaseB_A.2.stl
111.1 x 114.5 x 10.8

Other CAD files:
hardware/mechanical/print/plates/PLATE_RailType1_x2.3mf
hardware/mechanical/print/VESPA_Link_BracketLeft_A.1.stl
hardware/mechanical/print/VESPA_Turret_LaserMountFront_A.2.3mf
hardware/mechanical/print/VESPA_Turret_BearingPlate_A.1.stl
hardware/mechanical/print/VESPA_Camera_CarrierB_A.1.3mf
hardware/mechanical/print/VESPA_Frame_LinkC_A.3.stl
hardware/mechanical/print/VESPA_Link_BracketRight_A.1.stl
hardware/mechanical/print/VESPA_Turret_FrontShield_A.1.3mf
hardware/mechanical/print/VESPA_Turret_MotorMount_A.1.3mf
hardware/mechanical/print/VESPA_Turret_MotorPlate_A.1.stl
hardware/mechanical/print/VESPA_Turret_RailType1_A.2.3mf
hardware/mechanical/print/VESPA_Turret_RailType2_A.2.3mf
hardware/mechanical/print/VESPA_Turret_ShieldLite_A.1.stl
hardware/mechanical/print/VESPA_Turret_XFrame1Top_A.1.3mf

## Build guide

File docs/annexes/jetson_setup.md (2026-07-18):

# Annexe — Configuration du Jetson Orin Nano

> Cette étape **n'est pas optionnelle** : sans le noyau Arducam et les *overlays*, les
> caméras ne fonctionnent pas du tout.

---

## ⚠️ La règle numéro un

> ### Ne jamais exécuter `jetson-io.py`
>
> L'outil NVIDIA `sudo /opt/nvidia/jetson-io/jetson-io.py` régénère **globalement** les
> *overlays* d'arbre de périphériques. Il **écrase** la configuration existante au lieu de
> la compléter.
>
> Le lancer et sauvegarder **détruira la synchronisation stéréo** (l'overlay PWM), et
> possiblement la configuration caméra. C'est la raison pour laquelle toute la configuration
> matérielle de ce projet est portée par des *overlays* explicites et versionnés.

---

## 1. Système de base

1. Flasher **JetPack 6.2.1** (L4T r36.4) sur le Jetson Orin Nano Super 8 Go, via NVIDIA SDK
   Manager. La configuration d'origine a la racine sur **NVMe**.
2. Installer le **noyau et les pilotes Arducam** pour l'OV9281 (procédure du constructeur).
   Le noyau dédié est installé dans `/boot/arducam/`.

## 2. Overlays d'arbre de périphériques

Trois *overlays* sont chargés au démarrage. Les trois binaires sont dans
[`jetson/dts/`](../../jetson/dts/), avec les sources `.dts` des deux *overlays* propres au
projet.

| Overlay | Rôle | État |
|---|---|---|
| `tegra234-p3767-camera-p3768-arducam-dual.dtbo` | Double caméra OV9281 (un bus I²C par port CSI) | ✅ Fonctionne |
| `jetson-io-hdr40-user-custom.dtbo` | **PWM de synchronisation** — broches 32 et 33 | ✅ Fonctionne — **ne pas modifier** |
| `can0-pinmux.dtbo` | Routage du CAN0 (« CAN0 Hardware Override V5 »), broches 29/31 | ✅ Fonctionne |

### Contenu réel de `jetson-io-hdr40-user-custom.dtbo`

Source :
[`jetson/dts/jetson-io-hdr40-user-custom.dts`](../../jetson/dts/jetson-io-hdr40-user-custom.dts),
décompilée du binaire par `dtc -I dtb -O dts` (Jetson-IO ne produit pas de `.dts`).
L'*overlay* ne configure **que** deux broches :

```
hdr40-pin32  ->  soc_gpio19_pg6
hdr40-pin33  ->  soc_gpio21_ph0
```

**Il ne contient aucune configuration CAN.** Ce point est important : une hypothèse
répandue en fin de projet voulait que ce fichier contienne une mauvaise affectation CAN.
C'est faux. Ne pas perdre de temps à le « réparer » — et surtout ne pas le modifier, car
il porte le PWM de synchronisation.

## 3. `extlinux.conf`

Fichier de référence : [`jetson/extlinux.conf.reference`](../../jetson/extlinux.conf.reference).
L'entrée active (`DEFAULT JetsonIO`) :

```
LABEL JetsonIO
    MENU LABEL Custom Header Config: <CSI Camera ARDUCAM Dual>
    LINUX /boot/arducam/Image
    FDT   /boot/arducam/dts/dtb/tegra234-p3768-0000+p3767-0005-nv-super.dtb
    INITRD /boot/initrd
    APPEND ${cbootargs} root=PARTUUID=<...> rw rootwait rootfstype=ext4 ...
    OVERLAYS /boot/arducam/dts/tegra234-p3767-camera-p3768-arducam-dual.dtbo,/boot/jetson-io-hdr40-user-custom.dtbo,/boot/can0-pinmux.dtbo
```

> Adapter le `PARTUUID` à votre disque.

## 4. Vérifications

```bash
# Caméras : deux nœuds doivent apparaître
ls /dev/video*                    # -> /dev/video0  /dev/video1
v4l2-ctl --list-devices

# PWM de synchronisation
ls /sys/class/pwm/pwmchip3/

# CAN physique : overlay présent et broches routées
find /boot -name "*can*.dtbo"
#   -> /boot/can0-pinmux.dtbo ; sinon recopier depuis jetson/dts/
sudo bash -c "cat /sys/kernel/debug/pinctrl/*/pinmux-pins | grep -i paa"
#   -> pin 0 (CAN0_DOUT_PAA0): c310000.mttcan
```

## 5. Synchronisation stéréo (PWM)

Les deux caméras sont forcées en **mode esclave** (`trigger_mode=1`) et reçoivent le même
front de déclenchement, généré par le **PWM matériel du Tegra** — indépendant de la charge
CPU. C'est ce qui garantit une simultanéité *par construction*.

```bash
# 60 Hz, rapport cyclique 10 %
echo 0        > /sys/class/pwm/pwmchip3/export
echo 16666666 > /sys/class/pwm/pwmchip3/pwm0/period      # ns  -> 60 Hz
echo 1666666  > /sys/class/pwm/pwmchip3/pwm0/duty_cycle  # ns  -> 10 %
echo 1        > /sys/class/pwm/pwmchip3/pwm0/enable
```

C'est exactement ce que fait `HardwareSyncController::armTrigger()`. Dérive inter-caméras
mesurée : **0,000 ms**.

## 6. Bus CAN

### Virtuel (`vcan0`) — pour développer sans matériel

Le module est chargé au démarrage par [`jetson/systemd/vcan.conf`](../../jetson/systemd/vcan.conf) :

```bash
sudo modprobe vcan
sudo ip link add dev vcan0 type vcan
sudo ip link set up vcan0
candump vcan0
```

`vcan0` est indiscernable d'un bus réel du point de vue de SocketCAN : le code applicatif est
identique.

### Physique (`can0`) — a fonctionné, à remettre en service

Le service [`jetson/systemd/can0-setup.service`](../../jetson/systemd/can0-setup.service)
est prêt (500 kbit/s, `restart-ms 500`).

**Le bus a réellement fonctionné** : le 21 mars 2026, le Jetson a reçu **111 909 trames du
STM32, sans une seule erreur** (`RX: 772684 bytes, 111909 packets, 0 errors`). Le *pinmux*,
le câblage, la terminaison et le *bit timing* étaient donc corrects.

**Câblage** — ⚠️ dépend de l'authenticité du transceiver (voir [`bom.md`](bom.md)) :

| WCMCU-230 | En-tête 40 broches | Remarque |
|---|---|---|
| Alim. | broche 1 (3,3 V) **ou** broche 2 (5 V) | **5 V si le module est un clone** |
| `GND` | broche 6 | |
| `CTX` | broche **31** (CAN0_TX) | direct — le 3,3 V du Jetson suffit |
| `CRX` | broche **29** (CAN0_RX) | **pont diviseur 1 kΩ / 2 kΩ si clone 5 V** |

**Ce qui reste à faire.** Remonter les transceivers selon le câblage ci-dessus, puis
valider l'émission Jetson → STM32 (seule la réception l'a été).

> ⚠️ **Une mise à jour de JetPack peut supprimer le `.dtbo` sans toucher à la ligne
> `OVERLAYS` qui le référence.** Le *bootloader* n'émet alors **aucune erreur** : `can0`
> existe toujours, mais ses broches ne sont plus routées et le bus est muet. **C'est ainsi
> que le bus a été perdu.** Revérifier après chaque mise à jour.

Analyse complète et solution de repli (contrôleur CAN externe sur SPI) dans
**`docs/Difficultes_techniques.pdf`**.

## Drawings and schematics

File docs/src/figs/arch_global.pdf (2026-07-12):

## Vision

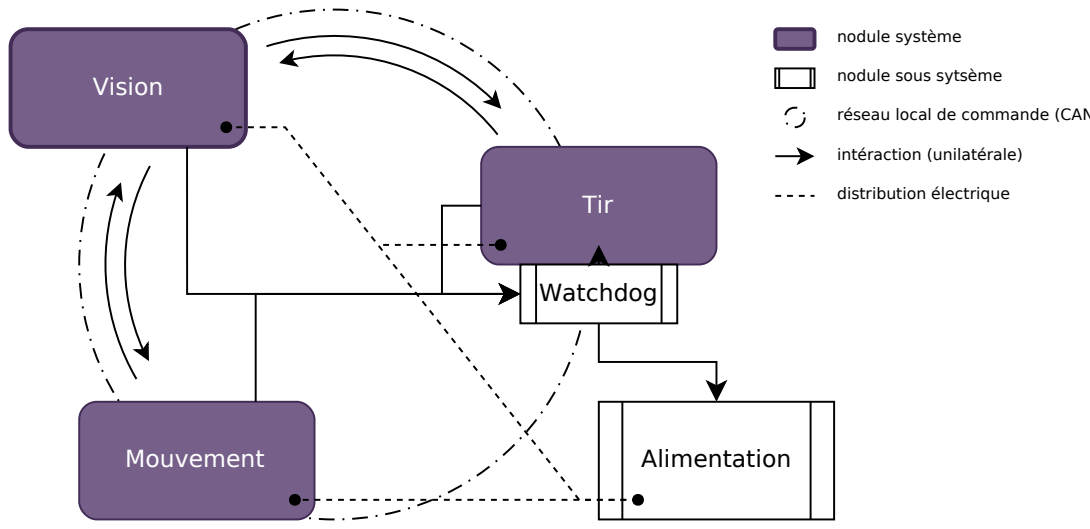
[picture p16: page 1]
Tir; Mouvement; Watchdog; Alimentation; nodule système; intéraction (unilatérale); distribution électrique

nodule sous sytsème

réseau local de commande (CAN

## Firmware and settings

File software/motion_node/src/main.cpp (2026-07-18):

#include <Arduino.h>
#include <SPI.h>
#include <SimpleFOC.h>
#include <IWatchdog.h>
#include "pinout.h"

#include "motion_can.h"
#include "can_utils.h"

// --- GM5208-12 GIMBAL PARAMETERS ---
const int   POLE_PAIRS = 7; 
const float RS_OHMS    = 7.476f;
const float LS_HENRYS  = 0.00449f;
const float KV_RATING  = 21.4f;

// --- CALIBRATION VALUES ---
const float PAN_ZERO_ANGLE  = 0.2684f; 
const Direction PAN_DIR     = Direction::CW; 
const float TILT_ZERO_ANGLE = 0.7543f; 
const Direction TILT_DIR    = Direction::CW;

volatile bool estop_triggered = false;

// --- HARDWARE OBJECTS ---
MagneticSensorSPI encoderPan  = MagneticSensorSPI(AS5048_SPI, ENC1_CS);
MagneticSensorSPI encoderTilt = MagneticSensorSPI(AS5048_SPI, ENC2_CS);

BLDCDriver3PWM driverPan  = BLDCDriver3PWM(M1_INU, M1_INV, M1_INW, M1_EN_FAULT);
BLDCDriver3PWM driverTilt = BLDCDriver3PWM(M2_INU, M2_INV, M2_INW, M2_EN_FAULT);

BLDCMotor motorPan  = BLDCMotor(POLE_PAIRS, RS_OHMS, KV_RATING, LS_HENRYS);
BLDCMotor motorTilt = BLDCMotor(POLE_PAIRS, RS_OHMS, KV_RATING, LS_HENRYS);

MotionCan canBus(CAN_RX, CAN_TX);
CAN_Frame_t rxFrame;

// --- LIMITS & OFFSETS ---
const float PAN_HARDCODED_OFFSET  = 0.00f; 
const float TILT_HARDCODED_OFFSET = 0.00f; 

const float PAN_MIN_LIMIT  = -0.52f;
const float PAN_MAX_LIMIT  =  0.52f;
const float TILT_MIN_LIMIT = -0.26f;
const float TILT_MAX_LIMIT =  0.78f;

float pan_base_target  = 0.0f;
float tilt_base_target = 0.0f;

// --- LATEST VISION TARGET (decoded from the CAN TARGET_VEC frame) ---
float vision_pan_rad  = 0.0f;
float vision_tilt_rad = 0.0f;
uint16_t vision_depth_mm = 0;
uint8_t vision_locked = 0;

// --- CAN BUS FAULT DETECTION ---
// If the Jetson stops ACKing our POS_MOTION frames for this many consecutive
// transmits (20 Hz => ~5 s), we flag a bus fault: the servo freezes on its last
// commanded angle and the heartbeat reports WARNING instead of OK.
const uint32_t CAN_TX_FAULT_THRESHOLD = 100;
uint32_t consecutive_tx_failures = 0;
bool bus_fault = false;

// --- TX TRACKING VARIABLES (For Monitor) ---
int16_t last_tx_pan = 0;
int16_t last_tx_tilt = 0;
bool last_pos_tx_success = false;
bool last_hb_tx_success = false;

// --- FILTERS ---
LowPassFilter filter_pot_pan  = LowPassFilter(0.05f);
LowPassFilter filter_pot_tilt = LowPassFilter(0.05f);
LowPassFilter trajectory_pan  = LowPassFilter(1.5f);
LowPassFilter trajectory_tilt = LowPassFilter(1.5f);

void emergencyStopISR() {
  estop_triggered = true;
  digitalWrite(M1_EN_FAULT, LOW); 
  digitalWrite(M2_EN_FAULT, LOW); 
}

void setup() {
  Serial.begin(115200);
  
  pinMode(USER_BUTTON, INPUT); 
  attachInterrupt(digitalPinToInterrupt(USER_BUTTON), emergencyStopISR, RISING);
  delay(2000); 
  
  pinMode(ENC1_CS, OUTPUT);  digitalWrite(ENC1_CS, HIGH);
  pinMode(ENC2_CS, OUTPUT);  digitalWrite(ENC2_CS, HIGH);
  pinMode(SPI1_NSS, INPUT_PULLUP); 
  pinMode(POT_PAN, INPUT);
  pinMode(POT_TILT, INPUT);

  SPI.begin();
  encoderPan.init(&SPI);
  encoderTilt.init(&SPI);
  motorPan.linkSensor(&encoderPan);
  motorTilt.linkSensor(&encoderTilt);

  driverPan.voltage_power_supply = 24.0f;
  driverPan.init();
  motorPan.linkDriver(&driverPan);

  driverTilt.voltage_power_supply = 24.0f;
  driverTilt.init();
  motorTilt.linkDriver(&driverTilt);

  motorPan.controller  = MotionControlType::angle;
  motorTilt.controller = MotionControlType::angle;

  motorPan.current_limit  = 1.0f; 
  motorPan.velocity_limit = 10.0f; 

  motorTilt.current_limit  = 1.0f; 
  motorTilt.velocity_limit = 10.0f;

  motorPan.P_angle.P = 4.0f;
  motorPan.P_angle.I = 0.5f;  
  motorPan.P_angle.D = 0.0f;
  motorPan.LPF_velocity.Tf = 0.005f; 

  motorTilt.P_angle.P = 6.0f; 
  motorTilt.P_angle.I = 0.6f; 
  motorTilt.P_angle.D = 0.00f; 
  motorTilt.LPF_velocity.Tf = 0.005f;

  motorPan.sensor_offset  = 4.7500f; 
  motorTilt.sensor_offset = 4.8179f;

  motorPan.init();
  motorTilt.init();

  Serial.println("\n--- Initializing FOC silently ---");
  motorPan.zero_electric_angle = PAN_ZERO_ANGLE;
  motorPan.sensor_direction    = PAN_DIR;
  motorPan.initFOC(); 

  motorTilt.zero_electric_angle = TILT_ZERO_ANGLE;
  motorTilt.sensor_direction    = TILT_DIR;
  motorTilt.initFOC(); 

  if (canBus.begin()) {
    Serial.println("=== CAN BUS INITIALIZED SUCCESSFULLY ===");
  } else {
    Serial.println("!!! CAN BUS INIT FAILED !!!");
  }

  // Arm the independent hardware watchdog LAST, once every blocking init step
  // (delay, initFOC, CAN) is done. From here loop() must refresh it within the
  // timeout or the MCU resets — this catches a firmware hang that would
  // otherwise leave the PWM frozen with only the physical e-stop as a net.
  IWatchdog.begin(200000); // 200 ms

  Serial.println("=== SYSTEM READY. SILENT STARTUP SUCCESS ===");
  Serial.flush();
}

void loop() {
  // Refresh the watchdog once per normal iteration.
  IWatchdog.reload();

  if (estop_triggered) {
    motorPan.disable();
    motorTilt.disable();

    HeartbeatPayload_t hbPayload;
    hbPayload.system_state = 0x02;
    CAN_Frame_t txFrame;
    if (CAN_Encode_Heartbeat(&txFrame, CAN_ID_HB_MOTION, &hbPayload)) {
        canBus.sendFrame(&txFrame);
    }

    Serial.println("\n!!! EMERGENCY STOP TRIGGERED !!!");
    Serial.flush();
    // Latch: hold the drivers disabled forever. Keep petting the watchdog and
    // re-asserting the fault lines so this DELIBERATE stop is not undone by a
    // watchdog reset (which would re-run setup() and re-enable the motors).
    while (true) {
      IWatchdog.reload();
      digitalWrite(M1_EN_FAULT, LOW);
      digitalWrite(M2_EN_FAULT, LOW);
      delay(100);
    }
  }

  // 1. POLL CAN BUS FOR JETSON TARGETS
  if (canBus.readFrame(&rxFrame)) {
    TargetPayload_t target;
    if (CAN_Decode_TargetVec(&rxFrame, &target)) {
        vision_pan_rad  = target.pan_angle / ANGLE_SCALE_FACTOR;
        vision_tilt_rad = target.tilt_angle / ANGLE_SCALE_FACTOR;
        vision_depth_mm = target.depth_mm;
        vision_locked   = target.is_locked;

        // Follow the vision aim-point only while the tracker reports a valid
        // lock AND the bus is healthy; otherwise hold the last commanded angle.
        // The potentiometer stays an additive manual trim on top of this base
        // target (see section 2), so a future integrator can null it out.
        if (vision_locked && !bus_fault) {
            pan_base_target  = vision_pan_rad;
            tilt_base_target = vision_tilt_rad;
        }

        Serial.println("\n<<< [HOT RX] NEW TARGET DATA RECEIVED! >>>");
    }
  }

  // 2. POTENTIOMETER OVERRIDES
  float raw_pot_pan  = analogRead(POT_PAN);
  float raw_pot_tilt = analogRead(POT_TILT);
  float smooth_offset_pan  = filter_pot_pan(((raw_pot_pan / 1023.0f) * 0.5236f) - 0.2618f);
  float smooth_offset_tilt = filter_pot_tilt(((raw_pot_tilt / 1023.0f) * 0.5236f) - 0.2618f);

  // 3. TARGET CLAMPING
  float clamped_pan  = constrain(pan_base_target + PAN_HARDCODED_OFFSET + smooth_offset_pan, PAN_MIN_LIMIT, PAN_MAX_LIMIT);
  float clamped_tilt = constrain(tilt_base_target + TILT_HARDCODED_OFFSET + smooth_offset_tilt, TILT_MIN_LIMIT, TILT_MAX_LIMIT);

  // 4. EXECUTE FOC
  motorPan.target  = trajectory_pan(clamped_pan);
  motorTilt.target = trajectory_tilt(clamped_tilt);
  motorPan.loopFOC();
  motorPan.move();
  motorTilt.loopFOC();
  motorTilt.move();

  // 5. TRANSMIT POS_MOTION (20Hz)
  static unsigned long last_pos_tx = 0;
  if (millis() - last_pos_tx >= 50) {
      last_pos_tx = millis();
      MotionPosPayload_t posPayload;
      
      // Capture what we are sending for the monitor
      posPayload.current_pan  = (int16_t)(motorPan.shaft_angle * ANGLE_SCALE_FACTOR);
      posPayload.current_tilt = (int16_t)(motorTilt.shaft_angle * ANGLE_SCALE_FACTOR);
      last_tx_pan = posPayload.current_pan;
      last_tx_tilt = posPayload.current_tilt;

      CAN_Frame_t txFrame;
      if (CAN_Encode_MotionPos(&txFrame, &posPayload)) {
          // If this returns true, the Jetson is successfully ACKing frames!
          last_pos_tx_success = canBus.sendFrame(&txFrame);

          // Escalate on repeated send failure (no ACK => bus/peer down).
          if (last_pos_tx_success) {
              consecutive_tx_failures = 0;
              bus_fault = false;
          } else if (consecutive_tx_failures < 0xFFFFFFFFu) {
              if (++consecutive_tx_failures >= CAN_TX_FAULT_THRESHOLD) {
                  bus_fault = true; // freeze on last angle; report WARNING
              }
          }
      }
  }

  // 6. TRANSMIT HB_MOTION (1Hz)
  static unsigned long last_hb_tx = 0;
  if (millis() - last_hb_tx >= 1000) {
      last_hb_tx = millis();
      HeartbeatPayload_t hbPayload;
      hbPayload.system_state = bus_fault ? 0x01 : 0x00; // WARNING vs OK
      CAN_Frame_t txFrame;
      if (CAN_Encode_Heartbeat(&txFrame, CAN_ID_HB_MOTION, &hbPayload)) {
          last_hb_tx_success = canBus.sendFrame(&txFrame);
      }
  }

  // 7. DEBUG: PRINT COMPREHENSIVE TELEMETRY (2Hz)
  static unsigned long last_can_debug_tx = 0;
  if (millis() - last_can_debug_tx >= 500) {
      last_can_debug_tx = millis();
      
      Serial.print("[JETSON -> G431] RX Target | Pan: "); Serial.print(vision_pan_rad, 4);
      Serial.print(" rad | Tilt: "); Serial.print(vision_tilt_rad, 4);
      Serial.print(" rad | Lock: "); Serial.println(vision_locked);

      Serial.print("[G431 -> JETSON] TX Pos (20Hz) | Pan: "); Serial.print(last_tx_pan);
      Serial.print(" | Tilt: "); Serial.print(last_tx_tilt);
      Serial.print(" | Jetson ACK: "); Serial.println(last_pos_tx_success ? "OK" : "FAIL (No ACK / Bus Dead)");

      Serial.print("[G431 -> JETSON] TX Heartbeat (1Hz) | State: "); Serial.print(bus_fault ? "0x01 WARN" : "0x00 OK");
      Serial.print(" | Jetson ACK: "); Serial.println(last_hb_tx_success ? "OK" : "FAIL");
      Serial.println("---------------------------------------------------------");
  }
}

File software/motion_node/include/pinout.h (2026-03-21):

/**
 * @file pinout.h
 * @brief Hardware pin mapping for the VESPA Motion Node (Arduino/SimpleFOC compatible).
 */

#ifndef PINOUT_H
#define PINOUT_H

#include <Arduino.h>

/* ========================================================================= */
/* MOTOR 1 (PAN)                                                             */
/* ========================================================================= */
#define M1_INU PA8
#define M1_INV PA9
#define M1_INW PA10
#define M1_EN_FAULT PA11
#define POT_PAN PB14      // Fine-tuning potentiometer (Moved from PA2 for Serial TX)

// Current & Voltage Sensing (For future activation)
#define M1_SENSEU PA1
#define M1_SENSEV PB1
#define M1_SENSEW PA4     // WARNING: PA4 currently repurposed for SPI Hardware NSS Safety
#define M1_VBUS PA0


/* ========================================================================= */
/* MOTOR 2 (TILT)                                                            */
/* ========================================================================= */
#define M2_INU PC6
#define M2_INV PC7
#define M2_INW PC8
#define M2_EN_FAULT PB12
#define POT_TILT PB0      // Fine-tuning potentiometer

// Current & Voltage Sensing (For future activation)
#define M2_SENSEU PC0
#define M2_SENSEV PC1
#define M2_SENSEW PC2
#define M2_VBUS PC3


/* ========================================================================= */
/* AS5048A ABSOLUTE ENCODERS - SPI1                                          */
/* ========================================================================= */
#define SPI1_SCK PA5
#define SPI1_MISO PA6
#define SPI1_MOSI PA7
#define SPI1_NSS PA4      // Hardware NSS pin (Pulled HIGH for safety)
#define ENC1_CS PB6       // Pan Encoder CS
#define ENC2_CS PB7       // Tilt Encoder CS

/* ========================================================================= */
/* WCMCU-230 CAN TRANSCEIVER - FDCAN1                                        */
/* ========================================================================= */
#define CAN_RX PB8
#define CAN_TX PB9

/* ========================================================================= */
/* SYSTEM & SAFETY                                                           */
/* ========================================================================= */
#define USER_BUTTON PC13  // Hardware E-Stop trigger

#endif // PINOUT_H

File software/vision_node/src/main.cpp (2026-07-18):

/**
 * @file main.cpp
 * @brief Project VESPA - Vision Node (Production Master)
 */

#include <iostream>
#include <vector>
#include <fstream>
#include <string>
#include <atomic>
#include <csignal>
#include <cmath>
#include <algorithm>
#include <opencv2/opencv.hpp>
#include <nlohmann/json.hpp>

#include "HardwareSyncController.h"
#include "ArUcoTracker.h"
#include "StereoTriangulator.h"
#include "PredictiveTurretSight.h"
#include "config_path.h"

#include "vision_can.h"
#include "can_protocol.h"
#include "can_utils.h"

using json = nlohmann::json;
using namespace VESPA;

std::atomic<bool> keep_running(true);

void signalHandler(int)
{
    std::cout << "\n[VISION NODE] SIGINT received. Executing safe hardware teardown...\n";
    keep_running = false;
}

// --- HARDWARE ENDSTOPS (Radians) ---
const double MAX_PAN_RAD = 0.52;         // -30deg
const double MIN_PAN_RAD = -0.52;        // +30deg
const double MAX_TILT_RAD = 0.78;        // +45deg
const double MIN_TILT_RAD = -0.26;       // -15deg
const double FIRE_TOLERANCE_RAD = 0.035; // ~2.0 degrees

int main()
{
    std::signal(SIGINT, signalHandler);
    std::signal(SIGTERM, signalHandler);

    std::cout << "==========================================\n";
    std::cout << "      VESPA VISION NODE - PRODUCTION      \n";
    std::cout << "==========================================\n";

    // 1. BOOT NETWORK (Virtual Hardware Bus for Testing)
    VisionCan can_bus("can0");
    if (!can_bus.begin())
    {
        std::cerr << "[FATAL] SocketCAN interface failed to bind. Halting.\n";
        return -1;
    }
    std::cout << "[SYSTEM] CAN Bus [can0] Active.\n";

    // 2. BOOT OPTICS & MATH
    std::ifstream file(resolveConfigPath("stereovision_settings.json"));
    if (!file.is_open())
    {
        std::cerr << "[FATAL] Could not open stereovision_settings.json\n";
        return -1;
    }
    json calib;
    file >> calib;

    // Calibration is stored in the RAW landscape sensor frame (1280x800).
    float Fx_raw = calib["camera_matrix_left"][0][0];
    float Fy_raw = calib["camera_matrix_left"][1][1];
    float Cx_raw = calib["camera_matrix_left"][0][2];
    float Cy_raw = calib["camera_matrix_left"][1][2];
    float baseline_mm = std::abs((float)calib["T"][0][0]);

    // ArUcoTracker::detect() returns centroids in the UPRIGHT 800x1280 frame
    // (CCW 90 deg: upright_x = raw_y, upright_y = RAW_WIDTH - raw_x). The
    // triangulator and the sight must therefore use intrinsics expressed in that
    // SAME frame -- otherwise X/Y (and the resulting pan/tilt) are back-projected
    // against a principal point in the wrong coordinate system. Rotate them:
    const float RAW_WIDTH = 1280.0f;
    float Fx = Fy_raw;              // upright-x focal      = raw-y focal
    float Fy = Fx_raw;              // upright-y focal      = raw-x focal
    float Cx = Cy_raw;              // upright principal-x  = raw Cy
    float Cy = RAW_WIDTH - Cx_raw;  // upright principal-y  = RAW_WIDTH - raw Cx

    TriangulatorConfig t_config;
    t_config.baseline_mm = baseline_mm;
    t_config.focal_length_px = Fx;  // disparity/depth axis = upright-x = raw-y
    t_config.epipolar_tolerance_px = 150.0f;
    t_config.min_disparity_px = 1.0f;
    t_config.center_x_px = Cx;
    t_config.center_y_px = Cy;

    StereoTriangulator triangulator(t_config);
    ArUcoTracker tracker;
    PredictiveTurretSight sight(Fx, Fy, Cx, Cy, 0.15);

    HardwareSyncController hal("/dev/video0", "/dev/video1", resolveConfigPath("camera_settings.json"));
    if (!hal.initializeRig())
        return -1;
    hal.armTrigger();

    std::cout << "[SYSTEM] Optical Frontend Locked. Node is LIVE.\n";

    double current_motor_pan = 0.0;
    double current_motor_tilt = 0.0;
    uint32_t frame_counter = 0;

    // --- PRODUCTION CORE LOOP ---
    while (keep_running)
    {
        long current_time_ms = cv::getTickCount() / (cv::getTickFrequency() / 1000);

        // A. DRAIN CAN QUEUE
        CAN_Frame_t rx_frame;
        while (can_bus.readFrame(&rx_frame))
        {
            if (rx_frame.id == CAN_ID_POS_MOTION)
            {
                MotionPosPayload_t motion_pos;
                if (CAN_Decode_MotionPos(&rx_frame, &motion_pos))
                {
                    current_motor_pan = (double)motion_pos.current_pan / ANGLE_SCALE_FACTOR;
                    current_motor_tilt = (double)motion_pos.current_tilt / ANGLE_SCALE_FACTOR;
                }
            }
        }

        // B. ACQUIRE HARDWARE SENSORS
        auto frame_pair = hal.captureSynchronizedPair();
        if (!frame_pair.valid)
            continue;

        auto raw_left = tracker.detect(frame_pair.left_data, 1280, 800);
        auto raw_right = tracker.detect(frame_pair.right_data, 1280, 800);

        bool target_locked = false;
        TargetPayload_t tx_target = {0};
        FirePayload_t tx_fire = {0};

        // C. COMPUTE FIRING SOLUTION
        if (!raw_left.empty() && !raw_right.empty())
        {
            // Feed the upright detection centroids straight into the sparse
            // triangulator, as the validated reference pipeline does
            // (test_stereo_pipeline.cpp). NOTE: lens distortion is intentionally
            // NOT corrected in this sparse path -- the coefficients are defined
            // in the raw sensor frame while detect() already rotated the points,
            // so undistorting here would be geometrically wrong. See
            // docs/annexes/dette_technique.md before trusting an absolute angle.
            auto targets_3d = triangulator.triangulate(raw_left, raw_right);

            if (!targets_3d.empty())
            {
                auto closest = std::min_element(targets_3d.begin(), targets_3d.end(),
                                                [](const Target3D &a, const Target3D &b)
                                                { return a.Z < b.Z; });

                AimCommand cmd = sight.updateAndPredict(closest->X, closest->Y, closest->Z, current_time_ms);

                double safe_pan = std::clamp(cmd.pan_angle, MIN_PAN_RAD, MAX_PAN_RAD);
                double safe_tilt = std::clamp(cmd.tilt_angle, MIN_TILT_RAD, MAX_TILT_RAD);

                bool fire_auth = (std::abs(current_motor_pan - safe_pan) < FIRE_TOLERANCE_RAD) &&
                                 (std::abs(current_motor_tilt - safe_tilt) < FIRE_TOLERANCE_RAD);

                tx_target.pan_angle = (int16_t)(safe_pan * ANGLE_SCALE_FACTOR);
                tx_target.tilt_angle = (int16_t)(safe_tilt * ANGLE_SCALE_FACTOR);
                tx_target.depth_mm = (uint16_t)(std::clamp(closest->Z, 0.0f, 65535.0f));
                tx_target.is_locked = 1;
                tx_fire.fire_order = fire_auth ? 0x01 : 0x00;

                target_locked = true;
            }
        }
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

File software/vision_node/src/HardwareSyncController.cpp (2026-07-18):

/**
 * @file HardwareSyncController.cpp
 * @brief Implementation of the Master/Slave synchronization orchestrator.
 */

#include "HardwareSyncController.h"

namespace VESPA
{

    HardwareSyncController::HardwareSyncController(const std::string &leftDevice, const std::string &rightDevice, const std::string &configPath)
        : m_leftDevName(leftDevice), m_rightDevName(rightDevice), m_configPath(configPath), m_isArmed(false), m_lockFd(-1)
    {
        m_leftCam = new CameraInterface(m_leftDevName);
        m_rightCam = new CameraInterface(m_rightDevName);
    }

    HardwareSyncController::~HardwareSyncController()
    {
        disarmTrigger();
        delete m_leftCam;
        delete m_rightCam;

        // Cleanly release the OS hardware lock so other tools can run
        if (m_lockFd >= 0)
        {
            flock(m_lockFd, LOCK_UN);
            close(m_lockFd);
            std::cout << "[SYNC CONTROLLER] Hardware lock released." << std::endl;
        }
    }

    bool HardwareSyncController::acquireHardwareLock()
    {
        m_lockFd = open("/tmp/vespa_hardware.lock", O_CREAT | O_RDWR | O_CLOEXEC, 0666);
        if (m_lockFd < 0)
        {
            std::cerr << "[FATAL] Could not create or open /tmp/vespa_hardware.lock" << std::endl;
            return false;
        }

        if (flock(m_lockFd, LOCK_EX | LOCK_NB) < 0)
        {
            std::cerr << "\n\033[1;31m[FATAL BUS CONTENTION HAZARD]\033[0m" << std::endl;
            std::cerr << "[FATAL] Hardware is currently locked by another process (Likely Python Calibration Tool)." << std::endl;
            std::cerr << "[FATAL] Aborting boot sequence immediately to prevent sensor burnout." << std::endl;
            close(m_lockFd);
            m_lockFd = -1;
            return false;
        }

        std::cout << "[SYNC CONTROLLER] Exclusive hardware lock acquired." << std::endl;
        return true;
    }

    bool HardwareSyncController::initializeRig()
    {
        std::cout << "[SYNC CONTROLLER] Initializing Stereo Rig..." << std::endl;

        if (!acquireHardwareLock())
        {
            return false;
        }

        std::system("echo 0 > /sys/class/pwm/pwmchip3/export 2>/dev/null");
        std::this_thread::sleep_for(std::chrono::milliseconds(100));

        disarmTrigger();
        std::system("echo 16666666 > /sys/class/pwm/pwmchip3/pwm0/period 2>/dev/null");

        if (!m_leftCam->init() || !m_rightCam->init())
        {
            std::cerr << "[FATAL] Failed to open video nodes." << std::endl;
            return false;
        }

        // 1. Start the hardware streams FIRST to wake up the PLL clocks
        m_leftCam->startStream();
        m_rightCam->startStream();

        std::cout << "[SYNC CONTROLLER] Waiting 500ms for sensor clocks to stabilize..." << std::endl;
        std::this_thread::sleep_for(std::chrono::milliseconds(500));

        // 2. Load the JSON configurations into memory
        std::cout << "[SYNC CONTROLLER] Loading optical settings from: " << m_configPath << std::endl;
        m_leftCam->loadSettings(m_configPath, "camera0");
        m_rightCam->loadSettings(m_configPath, "camera1");

        // 3. APPLY SETTINGS (Bypassing V4L2 Cache via Automated Jiggle)
        std::cout << "[SYNC CONTROLLER] Applying optical settings to I2C subdevices..." << std::endl;
        m_leftCam->applySettings();
        m_rightCam->applySettings();

        // 4. Force Slave Mode
        std::cout << "[SYNC CONTROLLER] Forcing Left Camera to Slave Mode..." << std::endl;
        if (!forceSlaveMode(m_leftDevName))
            return false;

        std::cout << "[SYNC CONTROLLER] Forcing Right Camera to Slave Mode..." << std::endl;
        if (!forceSlaveMode(m_rightDevName))
            return false;

        std::this_thread::sleep_for(std::chrono::milliseconds(50));

        m_leftCam->flushQueue();
        m_rightCam->flushQueue();

        std::cout << "\033[1;32m[SYNC CONTROLLER] Bus Contention Cleared. Rig is Ready.\033[0m" << std::endl;
        return true;
    }

    bool HardwareSyncController::forceSlaveMode(const std::string &deviceNode)
    {
        std::string cmd = "v4l2-ctl -d " + deviceNode +
                          " -c override_capture_timeout_ms=30000" +
                          " -c disable_frame_timeout=1" +
                          " -c frame_timeout=12000" +
                          " -c trigger_mode=1";
        int ret = std::system(cmd.c_str());
        return (ret == 0);
    }

    void HardwareSyncController::armTrigger()
    {
        if (!m_isArmed)
        {
            std::cout << "[SYNC CONTROLLER] Arming 60Hz Hardware Trigger..." << std::endl;
            std::system("echo 1666666 > /sys/class/pwm/pwmchip3/pwm0/duty_cycle");
            std::system("echo 1 > /sys/class/pwm/pwmchip3/pwm0/enable");
            m_isArmed = true;
        }
    }

    void HardwareSyncController::disarmTrigger()
    {
        std::cout << "[SYNC CONTROLLER] Disarming Trigger." << std::endl;
        std::system("echo 0 > /sys/class/pwm/pwmchip3/pwm0/duty_cycle 2>/dev/null");
        std::system("echo 0 > /sys/class/pwm/pwmchip3/pwm0/enable 2>/dev/null");
        m_isArmed = false;
    }

    StereoPair HardwareSyncController::captureSynchronizedPair()
    {
        StereoPair pair;

        bool left_ok = m_leftCam->captureFrame(pair.left_timestamp_ms, pair.left_data, pair.left_index);
        bool right_ok = m_rightCam->captureFrame(pair.right_timestamp_ms, pair.right_data, pair.right_index);

        // Bound the re-alignment: a persistent timestamp drift must not spin this
        // loop indefinitely dropping frames. After the cap we give up on this pair.
        const int MAX_RESYNC_ATTEMPTS = 20;
        int attempts = 0;

        while (left_ok && right_ok)
        {
            double diff = pair.left_timestamp_ms - pair.right_timestamp_ms;

            if (std::abs(diff) <= 5.0)
            {
                pair.valid = true;
                return pair;
            }

            if (++attempts > MAX_RESYNC_ATTEMPTS)
                break;

            if (diff < 0)
            {
                m_leftCam->releaseFrame(pair.left_index);
                left_ok = m_leftCam->captureFrame(pair.left_timestamp_ms, pair.left_data, pair.left_index);
            }
            else
            {
                m_rightCam->releaseFrame(pair.right_index);
                right_ok = m_rightCam->captureFrame(pair.right_timestamp_ms, pair.right_data, pair.right_index);
            }
        }

        if (left_ok)
            m_leftCam->releaseFrame(pair.left_index);
        if (right_ok)
            m_rightCam->releaseFrame(pair.right_index);
        pair.valid = false;

        return pair;
    }
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

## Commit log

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2026-01-29 feat(comms): Implement SocketCAN wrapper and protocol validation
    - Added `VespaCAN` class for low-level SocketCAN handling (socket/bind/write).
    - Implemented `send_target_packet` with strict type safety checks.
    - Updated `CMakeLists.txt` to fix `GST_LIBRARIES` typo and include comms sources.
    - Expanded `test_protocol.cpp` to validate negative coordinates, max range, and precision limits.
    - Integrated CAN initialization into `main.cpp`.
    [main.cpp]
2026-01-29 feat(vision): implement VespaPipeline and metadata probes
    - Added VespaPipeline class to manage GStreamer lifecycle.
    - Constructed DeepStream graph: v4l2src (stereo) -> mux -> infer -> tracker.
    - Implemented custom pad probe to extract tracking metadata.
    - Added logic to filter Hornet class and push data to VespaWorker.
2026-02-08 Major Reboot
    Changes committed:
    modified: .gitignore
    new file: docs/Jetson Orin VESPAI Pipeline Design.pdf
    new file: hardware/optics/UC-788_Rev.B_OV9281.pdf
    deleted: software/builds/CMakeCache.txt
    deleted: software/builds/CMakeFiles/3.22.1/CMakeCCompiler.cmake
    deleted: software/builds/CMakeFiles/3.22.1/CMakeCXXCompiler.cmake
    deleted: software/builds/CMakeFiles/3.22.1/CMakeDetermineCompilerABI_C.bin
    deleted: software/builds/CMakeFiles/3.22.1/CMakeDetermineCompilerABI_CXX.bin
    deleted: software/builds/CMakeFiles/3.22.1/CMakeSystem.cmake
    deleted: software/builds/CMakeFiles/3.22.1/CompilerIdC/CMakeCCompilerId.c
    deleted: software/builds/CMakeFiles/3.22.1/C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
    [config_infer_primary.txt]
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2026-02-08 modified: .gitignore modified: .vscode/c_cpp_properties.json modified: .vscode/launch.json new file: init_architecture.sh deleted: software/CMakeLists.txt new file: software/vision_node/CMakeLists.tx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
2026-02-28 new file: project_vespa.code-workspace new file: software/Tools/calibration_tool/app.py new file: software/Tools/calibration_tool/templates/index.html modified: software/vision_node/CMakeLists.txt mo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
2026-03-02 modified: .gitignore modified: .vscode/settings.json modified: software/vision_node/CMakeLists.txt modified: software/vision_node/builds/CMakeFiles/CMakeOutput.log modified: software/vision_node/buil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
2026-03-10 modified: software/vision_node/CMakeLists.txt modified: software/vision_node/PWM_sync_start.sh modified: software/vision_node/builds/CMakeFiles/CMakeOutput.log modified: software/vision_node/builds/C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
2026-03-14 deleted: software/Tools/calibration_tool/app.py deleted: software/Tools/calibration_tool/templates/index.html new file: software/Tools/expogain_calibration/app_EG.py new file: software/Tools/expogain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
2026-03-14 new file: software/Tools/live_viewport/app_TR.py new file: software/Tools/live_viewport/run_liveviewport.sh new file: software/Tools/live_viewport/venv_liveview/lib64 new file: software/Tools/live_vi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
    [pyvenv.cfg]
2026-03-16 modified: .vscode/settings.json new file: docs/Observations on the colony activity of the Asian hornet Vespa velutina Lepeletier 1836 Hymenoptera Vespidae Vespinae in France.pdf new file: docs/divers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
2026-03-21 modified: software/Tools/live_viewport/app_TR.py modified: software/Tools/live_viewport/run_liveviewport.sh modified: software/vision_node/CMakeLists.txt modified: software/vision_node/config/.active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
2026-07-12 Clôture du projet : documentation, bibliographie et réorganisation
    Le projet est archivé en l'état pour être repris par une équipe suivante.
    Documents (français, LaTeX -> PDF, sources dans docs/src/) :
    - Rapport technique : guide de reproduction complet (matériel, système,
    firmware, calibration, mise en route).
    - Difficultés techniques : verrous levés (avec la cause racine et le
    correctif) et verrous reportés (avec l'état réel des tentatives).
    - Bibliographie : reconstituée, le dossier d'origine ayant été perdu.
    Métadonnées vérifiées sur les PDF eux-mêmes ; source BibTeX commentée.
    Corrections factuelles établies contre les sources primaires :
    - Le CAN0 du Jet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
    [ADEL_SK_Carrier_B_A.1.3mf, pyvenv.cfg]
2026-07-14 Correction du bus CAN, nomenclature as-built, CAO et bibliographie
    Le bus CAN physique a fonctionné : correction d'une affirmation fausse
    répétée dans tout le dépôt.
    Relevé du noyau du 21/03/2026 (ip -s link show can0, controleur reel
    c310000.mttcan) : RX = 111 909 trames, 0 erreur, soit ~1h30 de trafic
    POS_MOTION continu a 20 Hz recu du STM32 sur cuivre. L'emission, elle,
    partait en BUS-OFF (248 erreurs TX, 20 363 redemarrages).
    Cause racine de cette asymetrie : les transceivers WCMCU-230 sont des
    CONTREFACONS - clones 5 V vendus pour des SN65HVD230 3,3 V, boitiers
    ponces et re-marques au laser. La sortie 5 V du module attaquait sans
    peine l'entree 3,3 V du Jetson (reception parfai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
    [ADEL_SK_Carrier_B_A.1.3mf]
2026-07-14 Bibliographie : sourcer les valeurs biologiques du dimensionnement laser
    Les constantes de létalité de Laser_Optics_v1.m (fluence létale, durée
    d'exposition, choix du bleu) n'étaient rattachées à aucune source. La
    section « Biologie de la cible » ne couvrait que morphologie, colonie,
    niche et parasites — rien sur la létalité thermique ni sur la dose optique.
    Ajout de quatre références réelles (métadonnées relevées sur la première
    page de chaque PDF, conformément à la convention de la bibliographie) :
    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
2026-07-14 Bibliographie : réduire à Keller et al. 2020 (source du dimensionnement laser)
    Suite à revue : on ne garde que Keller et al. 2020 (Photonic Fence,
    Sci. Rep. 10:14795), la seule source réellement sur le sujet — elle fonde
    le choix du bleu et la durée d'impulsion de 20 ms.
    - Retrait de Ruiz-Cristi 2020, Ono 1995 et Keller 2016, jugées hors sujet.
    - Retrait de toute la prose ajoutée : securite_laser.md et
    Laser_Optics_v1.m reviennent à l'identique. L'objectif était de sourcer,
    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
2026-07-14 Bibliographie : retirer les dernières traces du cadrage « reconstituée »
    L'en-tête de vespa.bib et deux mentions du README presentaient encore la
    bibliographie comme retablie apres coup. Remplace par ce qu'elle est : la
    source unique des references du projet, chacune annotee de ce qu'elle a
    determine.
    Integre au passage Keller et al. 2020 (Photonic Fence, Sci Rep 10:14795),
    merge par la PR #1 : metadonnees et DOI verifies sur la premiere page du
    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
2026-07-14 Nomenclature : retirer l'actionneur 10 mm, ajouter un total
    - Retire l'actionneur linéaire 10 mm : jamais monté sur le mk.2.
    - Ajoute une section « Total » en fin de nomenclature, avec sous-totaux
    par section.
    - Retire l'en-tête « Total relevé ≈ 830 € TTC » : ce chiffre ne se recoupe
    avec aucune lecture de la table (782,44 € en prix de ligne, 938,30 € en
    prix unitaires). Explicite au passage que la colonne « Prix TTC » est un
    prix de ligne.
    Les trois cartes ST (NUCLEO-G431RB, 2x X-NUCLEO-IHM16M1) restent non
    chiffrées : leur prix Farnell France n'est consigné nulle part et le total
    est marqué incomplet tant qu'il n'est pas relevé sur la facture.
2026-07-14 Nomenclature : chiffrer les cartes ST, total 840,74 EUR
    Prix relevés sur Farnell France, convertis en TTC (TVA 20 %) :
    - NUCLEO-G431RB : 18,40 HT -> 22,08 TTC (x1) -> 22,08
    - X-NUCLEO-IHM16M1 : 15,09 HT -> 18,11 TTC/unité (x2) -> 36,22
    Le total de la nomenclature est donc de 840,74 EUR TTC, et il est complet.
    Répercute les trois corrections (retrait de l'actionneur 10 mm, prix des
    cartes ST, total) dans le rapport technique, qui portait la même table, et
    republie docs/Rapport_technique.pdf.
    Retire le bloc d'avertissement « ce total est incomplet » : il n'a plus lieu
    d'être, et un document partagé n'est pas l'endroit où signaler ce genre de
    chose.
2026-07-14 Nomenclature : normaliser la mise en gras des tables
    Le gras était appliqué au coup par coup : les deux cartes ST et le couple
    GM5208-12 / AS5048A étaient en gras, mais pas le Jetson, ni le TMC2209, ni
    l'Arducam. Ce n'était donc ni « les composants importants », ni « les
    éléments critiques ».
    Le gras est désormais réservé à ce qu'un lecteur ne doit pas manquer :
    la diode laser (Classe 4), les lunettes de protection, et les transceivers
    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
2026-07-14 Mécanique : import de la CAO, des maillages et des plateaux d'impression
    Les 4 assemblages STEP exportés de 3DEXPERIENCE, les 19 maillages de pièces et
    les 6 projets PrusaSlicer, rangés dans hardware/mechanical/ et renommés à la
    convention VESPA_<Sous-ensemble>_<Pièce>_<Révision>.
    cad/ 4 assemblages AP242 : le démonstrateur 2 axes présenté, la tourelle
    complète WIP (Jetson + tube optique + collimation dynamique), l'embase
    WIP, la platine de banc électronique.
    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
    [PLATE_BearingMount_MotorMount.3mf, PLATE_FrontShield_flat.3mf, PLATE_FrontShield_tilted.3mf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]
2026-07-14 Mécanique : resserrer le README sur l'état des lieux
    Retrait des tournures prescriptives et des formulations qui décrivaient une
    intention plutôt qu'un fait : le README ne dit plus quoi faire des maillages
    manquants, il constate qu'ils sont absents.
2026-07-14 Nettoyage de clôture : code mort, figures orphelines, incohérences
    Audit du dépôt avant remise. Suppression de ce qui ne sert plus, correction
    de ce qui se contredisait, et intégration de ce qui existait sans être utilisé.
    Code mort (aucune référence dans tout le dépôt) :
    - tools/init_architecture.sh : script d'échafaudage qui générait un CAN.h avec
    un protocole faux (0x100/0x200/0x300/0x400), contredisant can_protocol.h.
    C'était un piège pour une équipe de reprise.
    - vision_node/include/{InferenceEngine,Orchestrator,Tracker}.h : stubs vides
    qu'il avait générés, jamais inclus, absents du CMakeLists.
    - vision_node/src/sparse_tracker.cpp : orphelin, remplacé par ste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
    [example_ContinuousSpeed.cpp, example_Oscillation_Homing.cpp]
2026-07-18 Corriger les points de l'audit de mise à disposition publique
    Traite les 6 bloquants et 15 "à corriger" de l'audit, plus la dette
    cosmétique réalisable sans réécrire l'historique.
    Bloquants:
    - B1 motion_node: la consigne CAN de vision pilote enfin les moteurs
    (base_target = cible, conditionnée au lock + santé du bus); variables
    test_* renommées vision_*; README honnête (servo OK, intégration
    vision→moteur câblée mais non validée sur banc).
    - B2 vision_node compile et démarre depuis un clone propre: nlohmann-json3-dev
    ajouté à la ligne apt; chemins /home/hytheh remplacés par un
    resolveConfigPath() partagé (config_path.h) dans main/stereo_t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
    [VESPA_ASY_Base_A.1_WIP.step, VESPA_Bench_BoardPlate_A.1.step, VESPA_Camera_CarrierB_A.1.3mf]
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2026-07-19 Docs : titres d'encadrés sur plusieurs lignes, chemins longs sécables, manifeste obsolète retiré du texte
    - vespa_style.sty : les titres flottants des encadrés tcolorbox passent à la
    ligne (varwidth boxed title) au lieu de déborder de la page.
    - Rapport_technique : nom complet de l'overlay Arducam dans le tableau des
    overlays (colonne élargie, césure explicite), chemins docs/ sécables dans
    l'introduction, avertissement PA2/PB14 reformulé en fait positif.
    - Difficultes_techniques : le correctif PA2 ne renvoie plus au fichier
    STM32_WiringManifest.txt (supprimé du dépôt à la clôture) mais à
    docs/annexes/cablage.md ; césure du nom d'overlay dans le tableau des
    affir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
2026-07-19 Docs : réaligner tous les documents sur le même état final
    - Rapport technique : la note CMake décrivait CUDA/VPI comme encore
    exigés (retirés depuis, ticket clos) ; nlohmann-json3-dev manquait
    dans les dépendances ; sparse_tracker absent du tableau des cibles ;
    URLs de calibration corrigées (localhost 5000/5001/5002 + tunnel SSH,
    les serveurs n'écoutent que sur 127.0.0.1) ; noms réels des profils
    (P2_dark, P3_bright) ; synthèse : l'overlay CAN est dans /boot.
    - Difficultés techniques : la synchro stéréo est l'œuvre du vision node
    (pas du motion node) ; compteur re-started 20 362 conforme au relevé ;
    procédure et synthèse ne demandent plus de réinstaller l'ov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
